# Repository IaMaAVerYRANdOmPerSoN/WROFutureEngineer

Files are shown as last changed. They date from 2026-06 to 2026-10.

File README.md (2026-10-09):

# WRO 2026 Future Engineers – TEAM APOSTLA

## Project Overview
This repository contains the complete documentation, code, design files, and test records for our **WRO 2026 Future Engineers** self-driving car project.

This repo is organized to show:
- how our robot is mechanically designed
- how power and sensors are arranged
- how the software is structured
- how engineering decisions were made
- how another team could reproduce the robot

---

## Team Members

<p align="center">
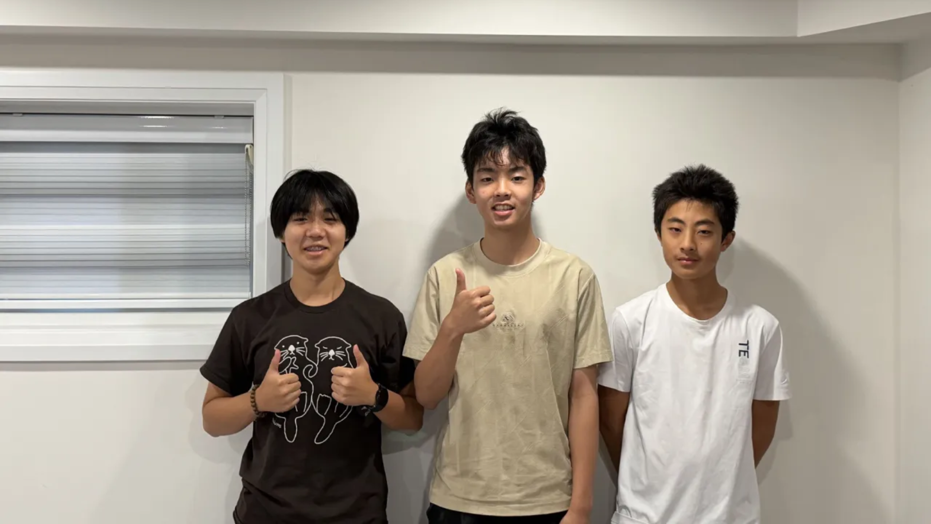
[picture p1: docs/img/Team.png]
  
</p>
<p align="center"><i>Explorer Robotics — WRO Future Engineers 2026</i></p>

---

We are a three-person team from Explorer Robotics in Whitby, Ontario, Canada. We have been competing in WRO for several years. This year we set out to build a fully autonomous self-driving robot from scratch, designing our own chassis, differential gear system, and vision pipeline.

## Elvis Wang
<table>
<tr>
  <td align="center" width="40%">
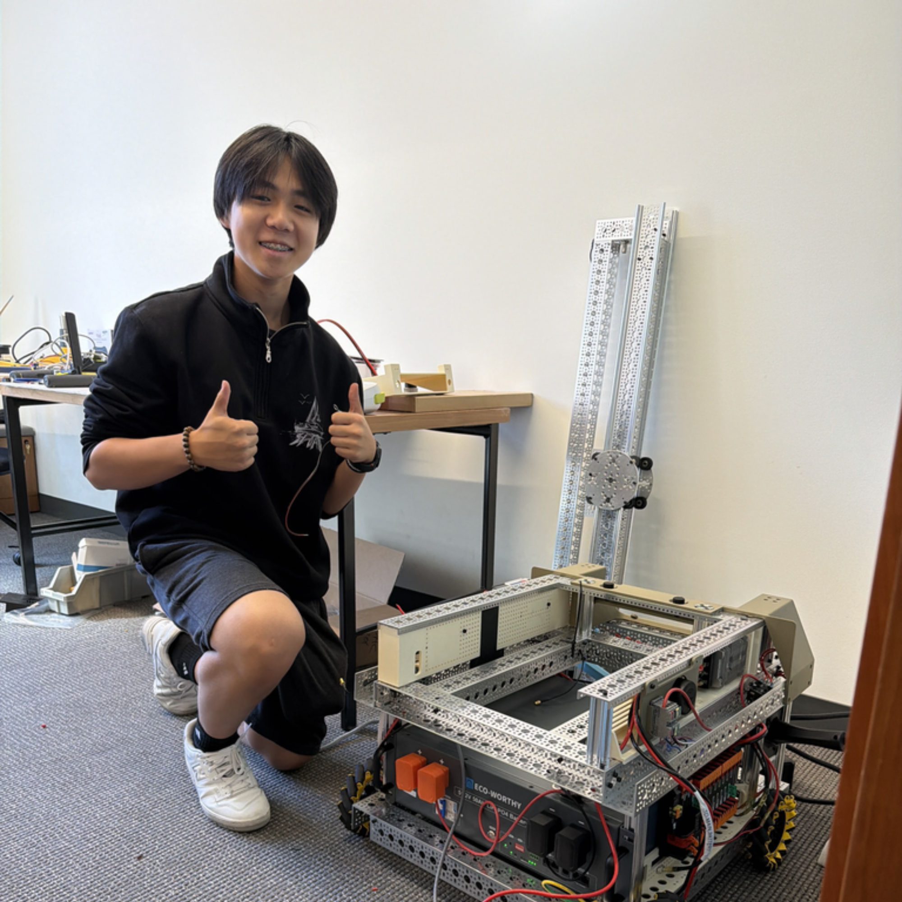
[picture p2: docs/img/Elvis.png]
    <br>
    <em>Elvis</em>
  </td>

  <td valign="top" width="60%">

  ### Information
  - *I love building!!!!!!!*
  - 15 years old
  - Hi, my name is Elvis. I'm 15. I enjoy building and 3D modeling various objects with Fusion 360. I've been with Explorer Robotics ever since I was 8 years old.
  </td>
</tr>
</table>

---

## Michael Xie
<table>
<tr>
  <td align="center" width="40%">
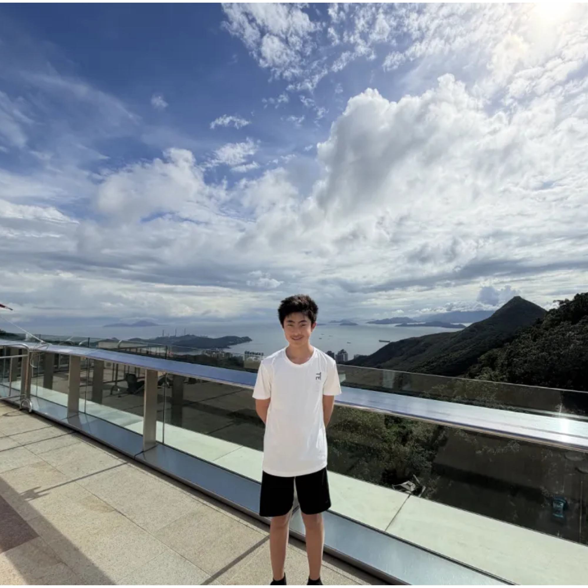
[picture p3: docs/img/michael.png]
    <br>
    <em>Michael</em>
  </td>

  <td valign="top" width="60%">

  ### Information
  - *I love coding!!!!!!*
  - 14 years old
  - I'm Michael. I'm 14, love coding and solving problems. I've been involved in WRO for several years and enjoy using my programming skills to help our team build and improve our robot.
  </td>
</tr>
</table>

---

## Ryan Rao
<table>
<tr>
  <td align="center" width="40%">
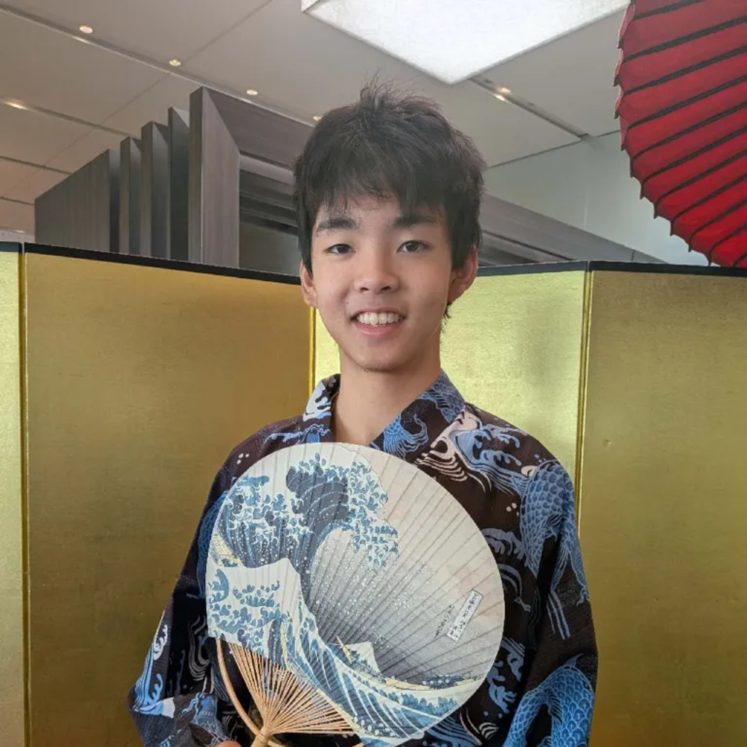
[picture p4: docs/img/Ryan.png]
    <br>
    <em>Ryan</em>
  </td>

  <td valign="top" width="60%">

  ### Information
  - *I love dogs*
  - 15 years old
  - Hi! I'm Ryan. I'm 15, love to write, play badminton, listen to music, and travel. I've been involved in robotics for nearly a decade and participated in both FLL and WRO Robo Mission.
  </td>
</tr>
</table>

## Coach Rice
<table>
<tr>
  <td align="center" width="40%">
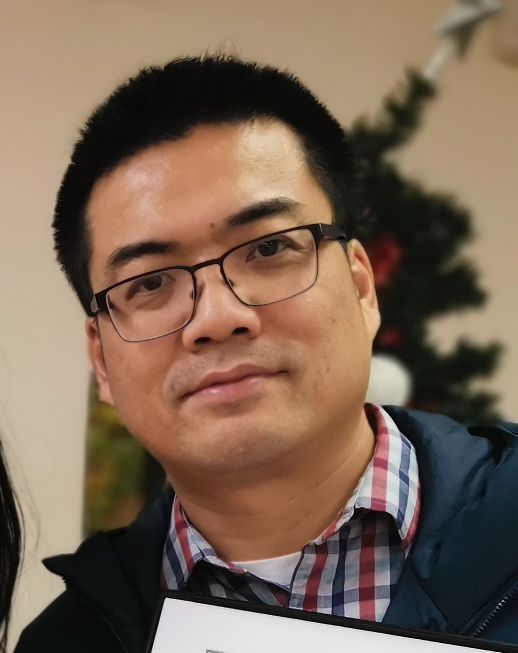
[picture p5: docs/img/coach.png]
    <br>
    <em>Coach Rice</em>
  </td>

  <td valign="top" width="60%">

  ### Information
  - Head coach of Robotics Competitions, including FLL (First LEGO League),  WRO (World Robotics Olympiad) Robo Sports, Future Engineers, and Robo Mission. Led teams in winning multiple national, international robotics, and programming awards.
  - Over 20 years of IT industry experience as a software engineer working internationally.
  - MSc in Electrical & Computer Engineering from the University of Alberta.
  - BSc in Mathematics from Peking University.
  - Founder of Explorer Robotics, a local robotics club in Ajax and Whitby, teaching coding, AI, robotics, etc.
  </td>
</tr>
</table>



---

## Robot Summary

> Our robot is a self-driving car built for the WRO 2026 Future Engineers challenge. It uses one downward-angled camera to spot track walls, corner lines, and colored obstacle pillars, and follows the track using a state-machine control loop. The robot runs on a Raspberry Pi 5 for vision, an Arduino Nano for motor and servo control, a Furitek Micro Komodo 1212 brushless motor that drives the rear wheels through a differential gearbox, and rack-and-pinion steering run by an HS-5055MG servo. Our design is simple and reliable, using one sensor for all detection and a sturdy build that's easy to fix during competition.

---

## Journal
- [View Journal](docs/journal/CHANGELOG.md)
- [View Journal PDF](docs/journal/CHANGELOG.pdf)

---

## Table of Contents

- [Project Overview](#project-overview)
- [Team Members](#team-members)
- [Robot Summary](#robot-summary)
- [Repository Structure](#repository-structure)
  - [Main Files](#main-files)
  - [Documentation](#documentation)
  - [Other Project Assets](#other-project-assets)
- [1. Mechanical Design](#1-mechanical-design)
  - [Images of Robot](#images-of-robot)
  - [Structural Design](#structural-design)
    - [Old Design](#old-design)
    - [Improvements](#improvements)
    - [Changes](#changes)
  - [3D Printed Parts](#3d-printed-parts)
  - [Full Robot](#full-robot)
- [2. Power and Sensor Architecture](#2-power-and-sensor-architecture)
  - [Power](#power)
  - [Voltage and Current Requirements](#voltage-and-current-requirements)
    - [5V Rail (Raspberry Pi, Arduino, Servo)](#5v-rail-raspberry-pi-arduino-servo)
    - [7.4V Rail (Motor)](#74v-rail-motor)
    - [Total Battery Power and Current](#total-battery-power-and-current)
    - [Runtime Estimate](#runtime-estimate)
  - [Sensors](#sensors)
  - [Compute](#compute)
  - [Summary](#summary)
- [3. Software Architecture and Strategy](#3-software-architecture-and-strategy)
  - [Software](#software)
  - [Architecture](#architecture)
  - [Config](#config)
  - [Vision](#vision)
    - [Wall Following](#wall-following)
    - [Obstacle Detection](#obstacle-detection)
  - [Hardware Interfaces](#hardware-interfaces)
  - [Challenge Running](#challenge-running)
    - [Open Challenge](#open-challenge)
    - [Obstacle Challenge](#obstacle-challenge)
  - [Running the Robot](#running-the-robot)
- [4. Systems Engineering and Design Decisions](#4-systems-engineering-and-design-decisions)
  - [Constraints](#constraints)
  - [Trade-offs](#trade-offs)
  - [Design Iteration](#design-iteration)
  - [Risk Analysis](#risk-analysis)
  - [Subsystem Interactions](#subsystem-interactions)
  - [Summary](#summary-1)
- [5. Reproducibility](#5-reproducibility)
  - [Software Setup](#software-setup)
  - [Hardware Setup](#hardware-setup)
  - [Testing](#testing)
  - [Summary](#summary-2)
- [Testing and Validation](#testing-and-validation)
- [Media and Visual Documentation](#media-and-visual-documentation)
  - [Diagrams](#diagrams)
  - [Videos](#videos)
- [CAD and Wiring Files](#cad-and-wiring-files)
- [Version History](#version-history)
- [Contribution and Documentation Rules](#contribution-and-documentation-rules)
- [Final Notes](#final-notes)
- [View Journal](docs/journal/CHANGELOG.md)

---
### GitHub Releases
[GitHub releases page](https://github.com/IaMaAVerYRANdOmPerSoN/WROFutureEngineer/releases/tag/v0.1.0)
- Source Code
- Cad File

---

## Repository Structure

### Main Files
- `README.md` – main project overview and navigation
- `LICENSE` – repository license
- `.gitignore` – ignored local/generated files
- `requirements.txt` – Python dependencies

### Documentation
- `docs/01_mechanical/` – mobility and mechanical design
- `docs/02_power_sensors/` – power system and sensor architecture
- `docs/03_software/` – software design and obstacle strategy
- `docs/04_systems_engineering/` – engineering decisions, trade-offs, and risks
- `docs/05_reproducibility/` – build, setup, assembly, and testing workflow
- `docs/journal/` – dated engineering journal (Markdown + PDF export)
- `docs/img/` – images referenced throughout the docs (robot photos, diagrams, team photos)
- `docs/plan.md`, `docs/shoppingList.md`, `docs/coach_comments.md` – supporting planning docs

**Other top-level folders:**
- `ArudinoServer/` – PlatformIO firmware for the Arduino (low-level motor/servo control)
- `PiClient/` – Python code on the Raspberry Pi
    - `src/` – main vision processing, control, and Arduino communication logic
    - `src_min/` – a minimal/leaner variant of the same modules
    - `utils/tools/` – standalone calibration and debug tools (contours, manual control)
    - `tests/` – test and experiment scripts
- `EDA/` – KiCad PCB project 
    - `FAB/` – fabrication outputs (Gerbers, BOM, pick-and-place positions)
    - `lib/` – imported component symbol/footprint libraries

---

# 1. Mechanical Design
This section explains the physical design of the robot, including chassis layout, steering, drivetrain, torque/speed reasoning, and mechanical improvements over time.

---

### Files
- [`docs/mechanical/mechanical_reasoning.md`](docs/01_mechanical/mechanical_reasoning.md)
- [`docs/mechanical/mechanical_iterations.md`](docs/01_mechanical/mechanical_iterations.md)
- [`docs/mechanical/torque_speed_reasoning.md`](docs/01_mechanical/torque_speed_reasoning.md)

---

- **Dimentions**: 24cm length 10cm wide 28cm high
    - [Dimentions reasoning](docs/01_mechanical/mechanical_reasoning.md#size-reasoning)
- **Drive Motor**: Furitek Micro Komodo 1212 Stepper Motor
    - [Motor reasoning](docs/01_mechanical/mechanical_reasoning.md#motor-selectionmotor-selection)
- **Steering Motor**: HS-5055MG 11.9g Metal Gear Digital Micro Servo
    - [Steering reasoning](docs/01_mechanical/mechanical_reasoning.md#servo-motor)

### Images of Robot
| | |
|:---:|:---:|
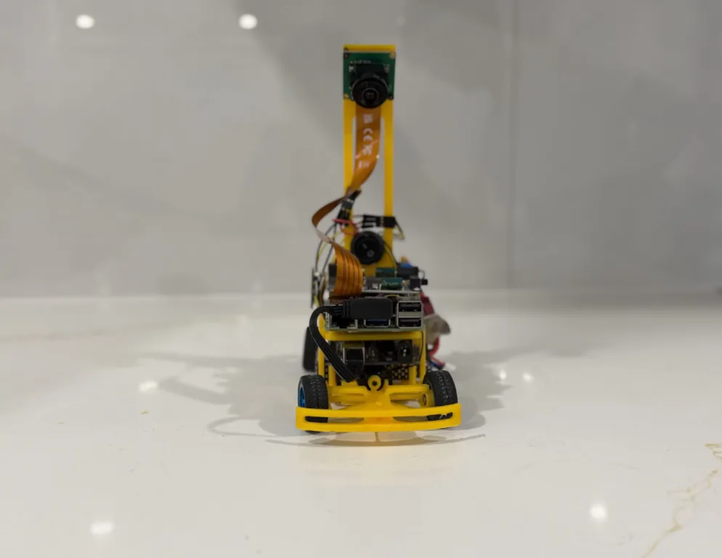
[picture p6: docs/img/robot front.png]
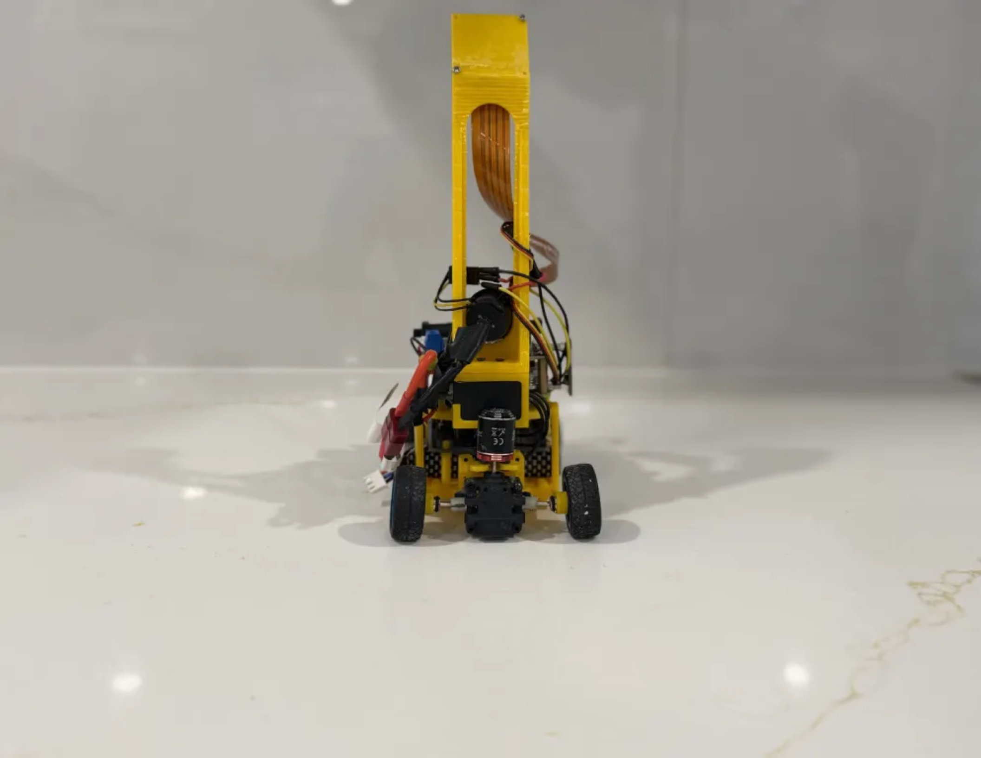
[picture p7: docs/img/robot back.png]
|  |  |
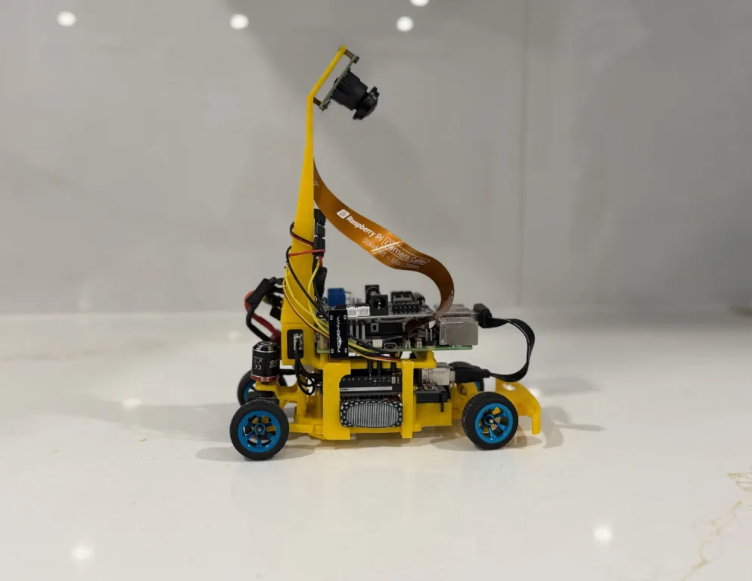
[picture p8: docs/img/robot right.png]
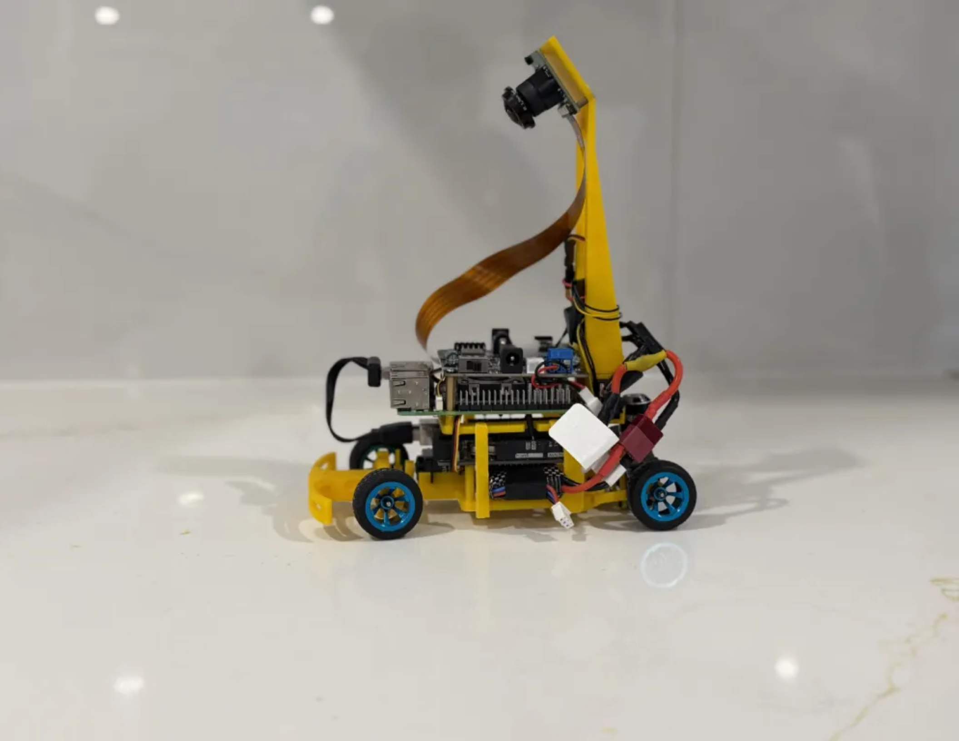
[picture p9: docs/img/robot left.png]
|  |  |
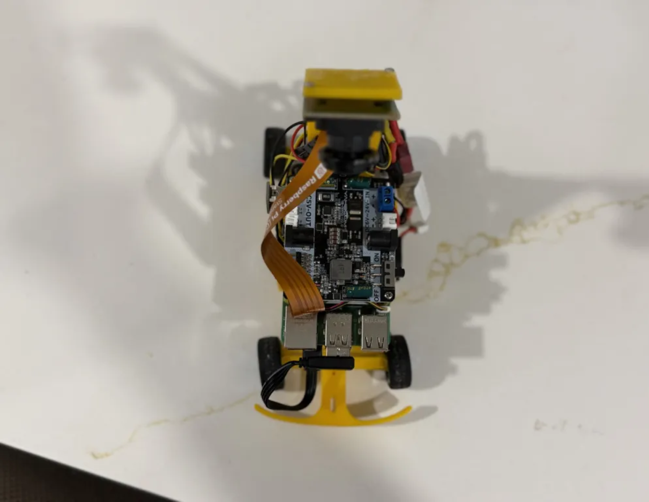
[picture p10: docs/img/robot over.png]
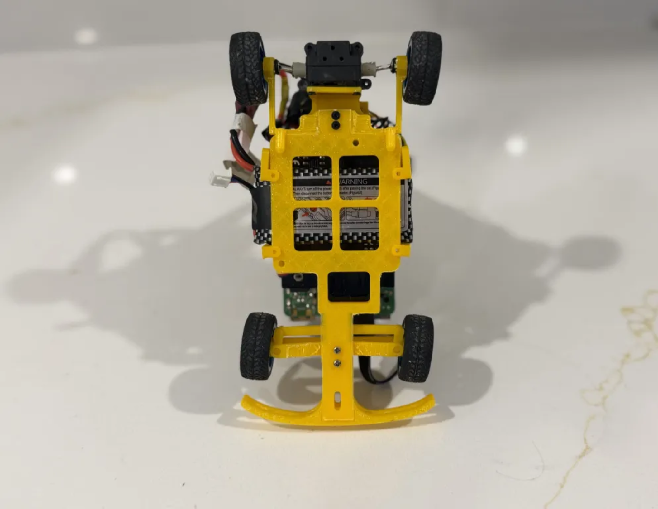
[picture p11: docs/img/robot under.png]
|  |  |

---

- **Drive System**: We use rear wheel drive, means the motor's power is transmitted to the back wheels rather than the front.
    - [Why RWD?](docs/01_mechanical/mechanical_reasoning.md#drive-system)
- **Steering type:** Parallel (Zero-Ackermann), Both front wheels turn at the same angle instead of the inner wheel turning more sharply than the outer. It does cause slight tire scrub during turns but it is acceptable on a small lightweight robot on a smooth mat.
    - [Why Parallel Zero-Ackermann?](docs/01_mechanical/mechanical_reasoning.md#steering-system)
### Structural Design
To get our current design, we took inspiration from our previous robot we used last year in Future Engineers.

#### Old Design
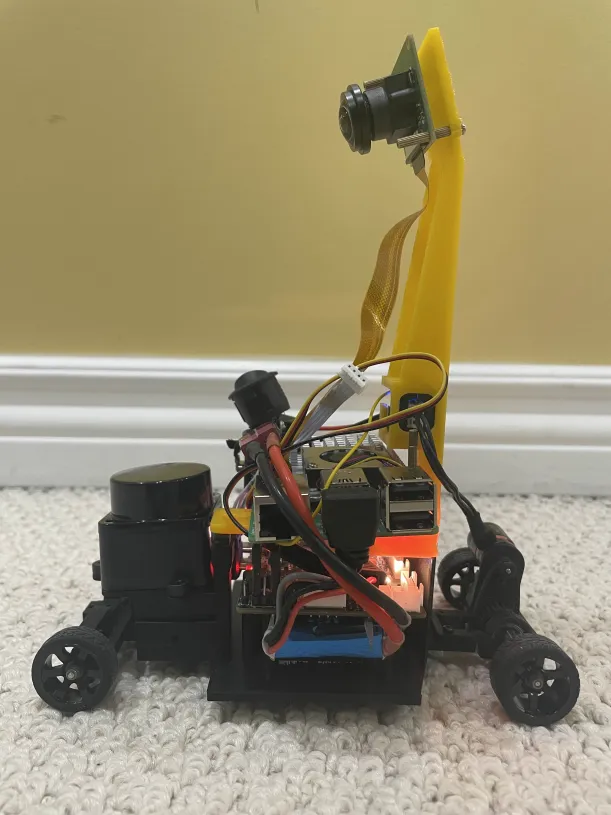
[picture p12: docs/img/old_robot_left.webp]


#### Improvements
- Make the robot thinner for more clearence and better weight distribution
- More supports on the sides of the robot (we only had 2)

---

#### Changes
- Rotating the Raspiberry Pi 90 degrees would allow for a slimmer design
- Implimenting more supports on the sides of the robot
- We use the Arduino Nano instead of Hiwonder
- Changed the camera angle and added a place for the stepdown voltage



### 3D Printed Parts

- **Turning System**: Servo-actuated rack and pinion steering with a curved front bumper for wall sliding in the obstacle challenge. The servo connects to the steering rack via a servo horn and tie rods, rotating the servo horn pushes or pulls the tie rods, which turn the front wheels left or right.
    - [Turning system iterations](docs/01_mechanical/mechanical_iterations.md#turning-system)

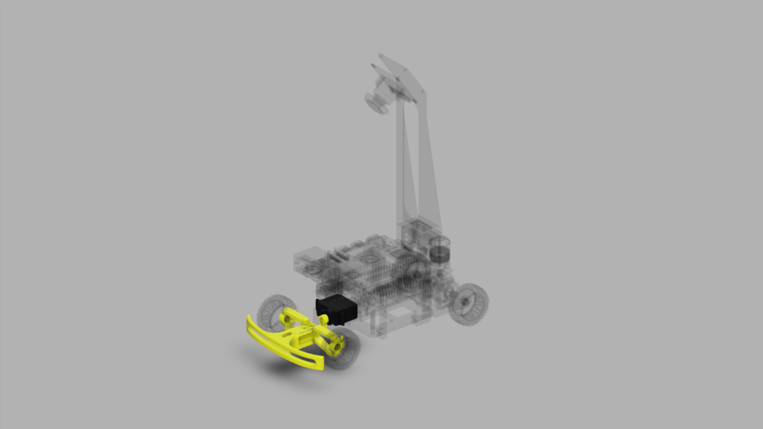
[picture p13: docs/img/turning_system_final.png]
Turning System


- **Raspberry Pi 5 Layout, Camera Mount, and ESC**: Slim rotated design with a separated camera tower angled at 35 degrees downward. The ESC is mounted inside the same assembly to keep electronics consolidated.
    - [RP5 layout and camera mount iterations](docs/01_mechanical/mechanical_iterations.md#raspberry-pi-5-layout-and-camera-mount)

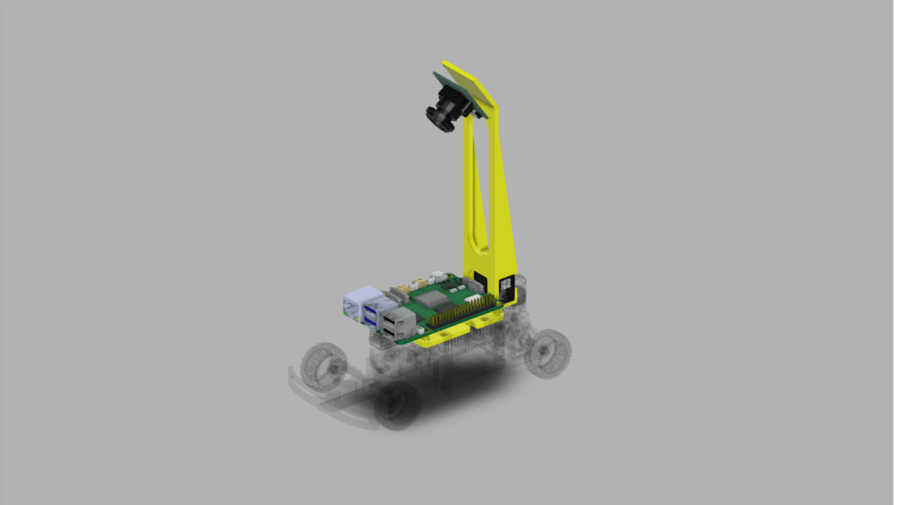
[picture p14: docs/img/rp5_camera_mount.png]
RP5 and Camera Mount


- **Arduino Nano Layout**: Main chassis plate holding the Arduino, servo, and front assembly; redesigned for compactness across four versions
    - [Arduino layout iterations](docs/01_mechanical/mechanical_iterations.md#europe-design)

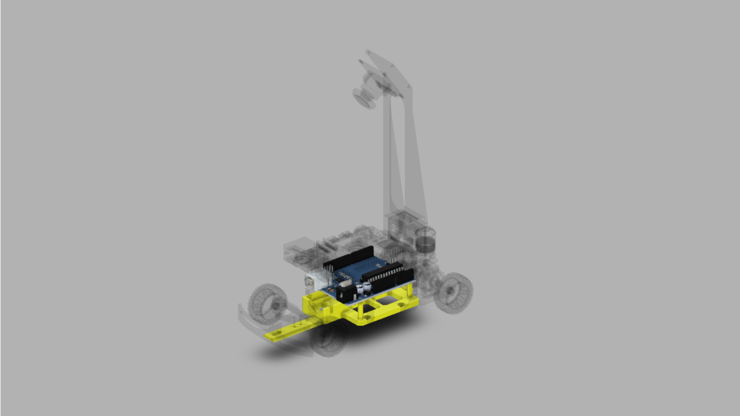
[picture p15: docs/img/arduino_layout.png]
Arduino Layout


- **Connectors**: 3D printed C-shaped connectors replacing brass standoffs to speed up assembly and disassembly
    - [Connector iterations](docs/01_mechanical/mechanical_iterations.md#connectors)

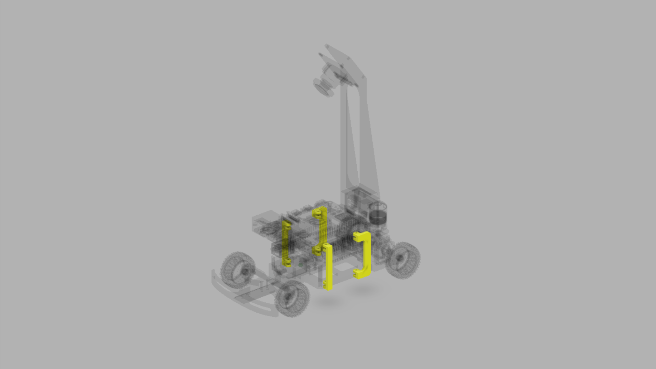
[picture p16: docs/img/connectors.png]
Connectors


- **Furitek Micro Komodo 1212**: Brushless motor rated at 3450 KV and 120W; drives the rear wheels through the differential gearbox
    - [Motor reasoning](docs/01_mechanical/mechanical_reasoning.md#motor-selection)

- **Differential Gear System**: Custom-designed differential allowing the rear wheels to spin at different speeds during turns; went through multiple iterations before settling on an off-the-shelf gearbox

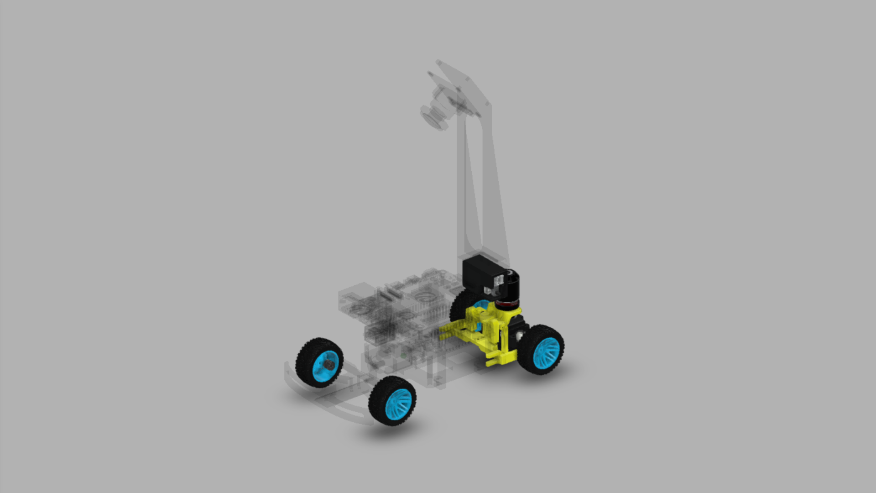
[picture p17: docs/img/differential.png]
Drivetrain


- **Wheels**: 35mm rubber wheels chosen to raise the chassis to give the differential adequate ground clearance
    - [Wheel and torque reasoning](docs/01_mechanical/torque_speed_reasoning.md)

- **Ball Bearings**: Four 6mm ball bearings pressed into the rear body mount to support the axles and reduce friction

---

### Full Robot

| | |
|:---:|:---:|
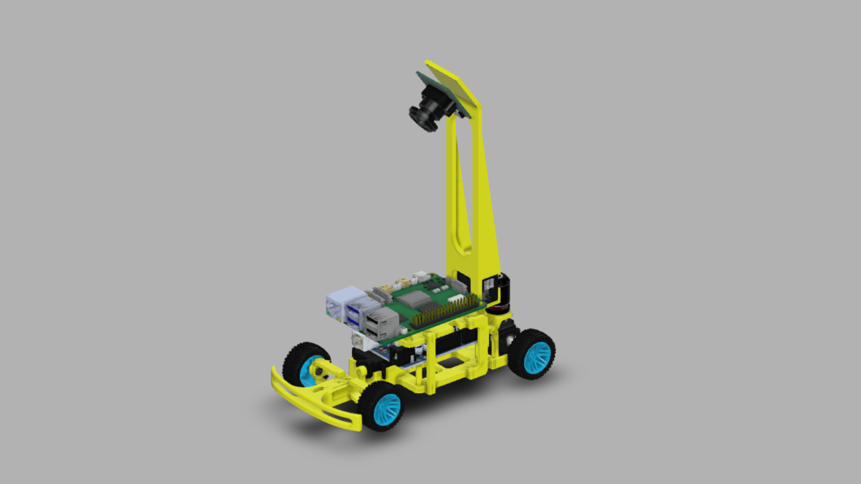
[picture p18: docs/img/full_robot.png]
Full Robot
|  |

---

### Assembly Video

Assembly Video (https://youtu.be/6nG1ul_CTjg)

---

# 2. Power and Sensor Architecture
This section explains how the robot is powered, what sensors are used, where they are placed, and how they are calibrated.

### Files
- [`docs/02_power_sensors/power_architecture.md`](docs/02_power_sensors/power_architecture.md)
- [`docs/02_power_sensors/sensor_selection.md`](docs/02_power_sensors/sensor_selection.md)
- [`docs/02_power_sensors/sensor_placement.md`](docs/02_power_sensors/sensor_placement.md)
- [`docs/02_power_sensors/calibration.md`](docs/02_power_sensors/calibration.md)

---

### Power

Everything starts with a single Gens Ace 1300mAh 2S LiPo battery. From there, power splits into two separate paths so the compute side and the actuator side never interfere with each other.

The first path goes through our Yahboom voltage regulator board, which steps the battery's 7.4V down to a clean 5V. That 5V feeds into the Raspberry Pi 5 through USB-C. The Arduino Nano doesn't connect to the battery at all, it gets powered straight from the Pi over a USB-B cable. The camera is also powered off the Pi, through its flat CSI ribbon cable, which carries both data and power in one connector.

The second path runs through the ESC. The ESC takes power directly from the battery and has its own built-in BEC (battery eliminator circuit) to regulate it. On the output side, the ESC's voltage pin powers the servo, and the ESC also drives the brushless motor directly since the motor doesn't need to be stepped down first.

<p align="center">
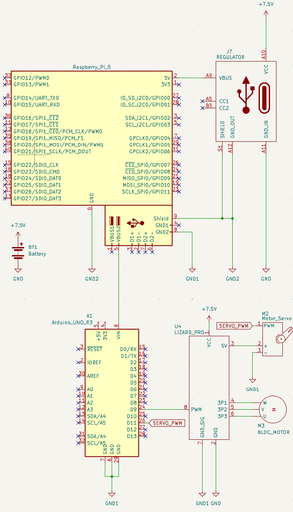
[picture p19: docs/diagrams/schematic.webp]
  
</p>
<p align="center"><i>Full electronics schematic showing power distribution and signal connections.</i></p>

The Raspberry Pi is the brain, it runs the vision pipeline, figures out where objects are, and decides what the robot should do next. The Arduino doesn't make any decisions, it just takes the drive commands the Pi sends it and turns them into precise PWM signals, since the Pi can't reliably time PWM output on its own while it's busy processing frames. The camera is the robot's only sense of the outside world, it feeds every frame the vision pipeline uses to find walls, corners, and pillars.

On the actuator side, the ESC handles throttle control for the drive motor based on the PWM signal it gets from the Arduino, and its BEC also acts as the power source for the servo, so the servo never has to touch the battery directly. The servo itself just turns the front wheels left and right based on the steering commands coming from the Arduino, and the motor is what actually moves the robot forward, spinning the rear wheels through the differential.

- **Battery**: Gens Ace 1300mAh 2S LiPo, 7.4V nominal, 45C discharge
    - [Battery details](docs/02_power_sensors/power_architecture.md#battery)
- **Voltage Regulation**: Yahboom regulator converts 7.4V to 5V for the Raspberry Pi; ESC built-in BEC powers the servo independently
    - [Regulator details](docs/02_power_sensors/power_architecture.md#design-rationale)
- **Main Power Switch**: Smaller switch installed on the main battery rail after the original 20A switch was replaced for easier integration
    - [Power design](docs/02_power_sensors/power_architecture.md#iterations)
- **Estimated Runtime**: ~17 minutes at average load; enough for ~5 full competition runs per charge

## Voltage and Current Requirements

### 5V Rail (Raspberry Pi, Arduino, Servo)

| Component | Current Draw |
|---|---|
| Raspberry Pi 5 | 2.40A |
| Arduino Nano | 0.05A |
| Servo Motor (stall) | 0.70A |
| Camera (OV5647) | 0.25A |
| **Total 5V current** | **3.40A** |

Power at 5V: 3.40A × 5V = **17W**

Accounting for regulator efficiency (80%):
17W ÷ 0.8 = **21.25W** needed from battery for the 5V rail.

---

### 7.4V Rail (Motor)

| Component | Current Draw |
|---|---|
| Drive Motor (average during run) | 3.50A |
| **Total motor current** | **3.50A** |

Power at 7.4V: 3.50A × 7.4V = **25.9W**

---

### Total Battery Power and Current

| Rail | Power |
|---|---|
| 5V rail (via regulator) | 21.25W |
| Motor rail (direct) | 25.9W |
| **Total** | **47.15W** |

Total current from battery:
47.15W ÷ 7.4V = **6.37A**

---

### Runtime Estimate

6.37A average draw from a 1300mAh (1.3Ah) battery at 80% usable capacity:

(1.3Ah × 0.8) ÷ 6.37A = **~0.16 hours (~10 minutes)**

In practice the robot lasts significantly longer because:
- The motor draws far less than stall current at competition speeds (30-40% throttle)
- The Raspberry Pi rarely hits full load simultaneously with peak motor draw
- The servo is at stall current only momentarily during sharp turns
- The regulator efficiency is typically closer to 85-90% under real load

At realistic average loads (~4A total), the expected runtime is approximately **17 minutes**, sufficient for ~5 full competition runs per charge.

Because of the decently short battery life, we have had between 4-5 batteries.

---

### Sensors

- **Camera (OV5647)**: Detects walls, corner lines, and colored pillars via CSI-2 at 640x480 up to 62.50 fps
    - [Camera selection](docs/02_power_sensors/sensor_selection.md#camera--ov5647)
    - [Camera placement](docs/02_power_sensors/sensor_placement.md)
- **IMU**: Detects rotation and acceleration
    - [IMU purpose](docs/02_power_sensors/sensor_selection.md#camera--ov5647)
      
---

### Compute

- **Raspberry Pi 5 (8GB)**: Main compute unit running the vision pipeline, control loop, and Arduino communication
    - [Raspberry Pi details](docs/02_power_sensors/sensor_selection.md#raspberry-pi-5-8gb)
- **Arduino Nano**: Handles PWM output to ESC and servo; receives drive commands from the Pi over USB serial
    - [Arduino details](docs/02_power_sensors/sensor_selection.md#arduino-nano)

---

### Actuators

- **ESC**: Furitek Lizard Pro 30A/50A ESC
    - [ESC reasoning](docs/02_power_sensors/power_architecture.md#electronic-speed-controller)
- **Drive Motor**: Furitek Micro Komodo 1212 Stepper Motor
    - [Motor reasoning](docs/01_mechanical/mechanical_reasoning.md#motor-selectionmotor-selection)
- **Steering Motor**: HS-5055MG 11.9g Metal Gear Digital Micro Servo
    - [Steering reasoning](docs/01_mechanical/mechanical_reasoning.md#servo-motor)
---

## Risks and Mitigation

- **Voltage drop:** The 45C discharge rating minimizes voltage sag under peak current draw. Battery voltage is monitored during practice runs to identify cell degradation early.
- **Brownout:** The Pi is powered through a Yahboom voltage regulator board rather than directly from the battery, isolating it from motor-induced voltage dips. A regulator with sufficient headroom above the Pi's peak draw was selected. We may have broken one of our raspberry pi's because we forgot the regulator...
- **Electrical noise:** Motor and ESC wiring are routed away from signal wires. The serial communication lines between the Pi and Arduino are kept short.
- **Loose connectors:** All connectors are secured with heat shrink. Once, one of our wires got caught in the gear system causing damage, leading to a short circuit. All wiring has since been replaced.
- **Overheating:** The ESC and motor are mounted with airflow clearance. Competition runs are under 3 minutes, well within thermal limits. The Raspberry Pi fan is configured to always run after the temperature sensor proved unreliable on our unit.
- **Power spikes from motors / servos:** The ESC BEC powers the servo independently from the motor rail. The dedicated regulator for the Pi prevents motor spikes from reaching the compute system.

---

### Summary
- battery: Gens Ace 1300mAh 2S LiPo (7.4V, 45C)
- voltage regulation: Buck regulator for Pi (5V); ESC BEC for servo
- main sensors: OV5647 camera (CSI-2)
- sensor placement strategy: Camera mounted at front with downward tilt for field of view
- calibration approach: HSV color thresholds tuned under competition lighting using interactive tuning tools in `utils/`

---

# 3. Software Architecture and Strategy

## Software

This section explains the software that runs on the Raspberry Pi, including how the processes are structured, how the robot detects walls and obstacles, and how drive commands are sent to the Arduino.

---

### Files
- [`docs/03_software/architecture.md`](docs/03_software/architecture.md)
- [`docs/03_software/challenge)running.md`](docs/03_software/challenge_running.md)
- [`docs/03_software/config.md`](docs/03_software/config.md)
- [`docs/03_software/hardware_interfaces.md`](docs/03_software/hardware_interfaces.md)
- [`docs/03_software/state_machine.md`](docs/03_software/state_machine.md)
- [`docs/03_software/vision.md`](docs/03_software/vision.md)

---

## Architecture

Three processes run at the same time, camera, vision, and main control. The camera writes frames into shared memory, the vision process reads them and finds walls and obstacles, and the main process runs the state machine and sends commands to the Arduino. The system always uses the freshest data; stale frames and commands are dropped automatically.

- **Camera Process**: Captures frames and writes them into shared memory
    - [Architecture details](docs/03_software/architecture.md)
- **Vision Process**: Reads frames and finds walls and obstacles
    - [Vision details](docs/03_software/vision.md)
- **Main Process**: Runs the state machine and sends drive commands to the Arduino
    - [Runner details](docs/03_software/challenge_running.md)

<p align="center">
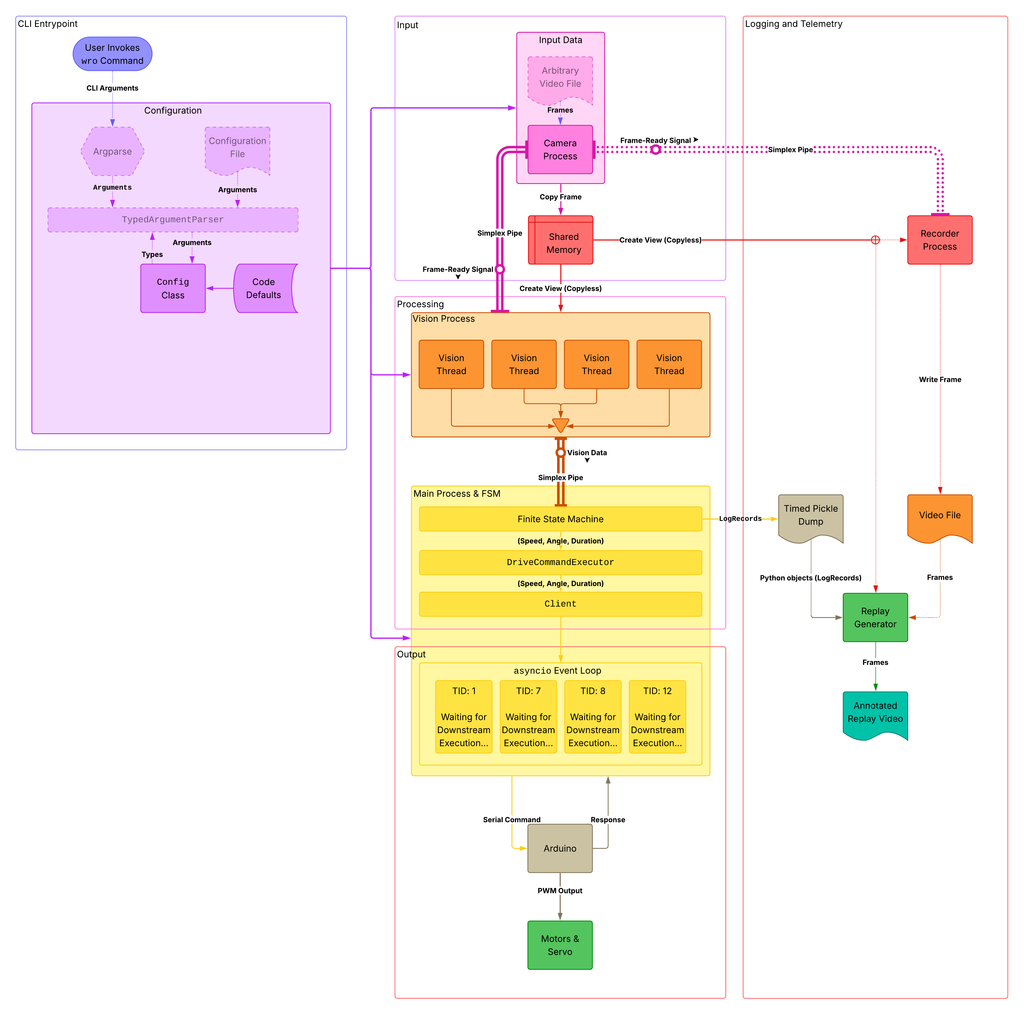
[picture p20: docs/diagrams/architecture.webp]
  
</p>
<p align="center"><i>Full software architecture diagram.</i></p>

---

## Config

All settings are stored in `piclient.toml`. Nothing is hardcoded — speed, PD gains, HSV thresholds, serial ports, and ROI sizes are all in the config file. Once the robot starts, the config is locked and cannot be changed mid-run.

- **Settings file**: `piclient.toml` at the root of the repo
    - [Config details](docs/03_software/config.md)
- **Override priority**: CLI flag > environment variable > `piclient.toml` > code defaults

---

## Vision

### Wall Following

`open_challenge.py:95-104` the vision pipeline counts the number of black pixels in the left, right, and center regions of the image. The difference between right and left distance is fed into a PD controller (`wall_follow.tick(right - left)`), and the output is sent as a steering command via `client.drive_motors(...)`. If the right wall is further than the left, the correction steers left, and vice versa. It only cares about relative position, not absolute distance, which is why the perspective transform can be skipped. Camera distortion does not change which wall is closer.

### Obstacle Detection

`vision_processing.py:100-106`: red and green pillars are found the same way as walls, but contours (as NumPy arrays) are used instead of simple pixel counts. Once a pillar is found, `_get_target` calculates a target x position by offsetting the pillar's x position proportionally to the width of the pillar. A separate PD controller (`obstacle_avoid`) steers toward that target x position rather than centering between walls, while maintaining 20% wall-follow weight to keep general awareness. This only runs in `obstacle_challenge.py`'s "obstacle_avoid" state, and only when `obstacles` is non-empty. Otherwise, it falls back to plain wall following.

- **Open Challenge**: Counts black pixels in left, right, and center regions. More black pixels means the wall is closer. Corner detection triggers when the center region fills up.
    - [Open challenge vision details](docs/03_software/vision.md#open-challenge)
- **Obstacle Challenge**: Finds red and green pillars using HSV color detection and calculates an offset target x position to steer toward the gap between the pillar and the wall.
    - [Obstacle challenge vision details](docs/03_software/vision.md#obstacle-challenge)

---

## Hardware Interfaces

- **Camera**: Runs in its own process, writes frames directly into shared memory with no copying
    - [Camera details](docs/03_software/hardware_interfaces.md#camera)
- **Arduino Client**: Sends serial commands with transaction IDs so multiple commands can be in flight at once
    - [Arduino client details](docs/03_software/hardware_interfaces.md#arduino-client)
- **DriveCommandExecutor**: Sits between the control loop and the Arduino, only the latest command is sent, stale commands are thrown away
    - [DriveCommandExecutor details](docs/03_software/hardware_interfaces.md#drivecommandexecutor)

---

## Challenge Running
The robot uses a finite state machine (FSM) to decide what to do at any given moment. Each state has a specific trigger that causes the robot to enter it and a specific action it takes while in that state. The FSM runs once per camera frame, so the robot is constantly re-evaluating which state it should be in based on the latest vision data.

### Open Challenge

| State | Trigger | Action |
|---|---|---|
| Straight | Default | Wall follow with PD controller |
| Turn | Black fill detected ahead | Hard steer toward missing wall |
| Final Turn | Last turn of last lap | Same as Turn |
| Final Straight | After final turn | Drive to stop |

- [Open challenge runner details](docs/03_software/challenge_running.md#open-challenge)

### Obstacle Challenge

| State | Trigger | Action |
|---|---|---|
| Straight | Default | Wall follow with PD controller |
| Turn | Corner detected | Hard steer toward missing wall |
| Obstacle Avoid | Vision returns a pillar target | Steers toward the gap between pillar and wall |
| Parallel Parking | Vision returns a parking lot target and the 3rd lap is complete | Steers toward the parking lot and executes a parallel parking maneuver |

Same as the open challenge with one extra state. When a pillar is detected, the robot steers toward the gap between the pillar and the wall. Green pillars are passed on the left, red on the right.

- [Obstacle challenge runner details](docs/03_software/challenge_running.md#obstacle-challenge)

---

## Running the Robot

```bash
wro --GeneralConfig.CHALLENGE open
wro --GeneralConfig.CHALLENGE obstacle
```

Full auto-generated API docs: https://apostla-api-reference.web.app/
---

# 4. Systems Engineering and Design Decisions
This section explains how the robot was developed as an integrated system and how trade-offs were evaluated.

- **Engineering Journal**:
The journal is best viewed on GitHub where all links are clickable. A PDF version is also available for submission.
    - [View Journal](docs/journal/CHANGELOG.md)
    - [View Journal PDF](docs/journal/CHANGELOG.pdf)

### Files
- [`docs/04_systems_engineering/subsystem_interactions.md`](docs/04_systems_engineering/subsystem_interactions.md)
- [`docs/04_systems_engineering/constraints_tradeoffs.md`](docs/04_systems_engineering/constraints_tradeoffs.md)
- [`docs/04_systems_engineering/risk_analysis.md`](docs/04_systems_engineering/risk_analysis.md)
- [`docs/04_systems_engineering/iteration_cycles.md`](docs/04_systems_engineering/iteration_cycles.md)

### Constraints

The robot must satisfy four levels of constraints in order of priority:

- **WRO rules compliance**: Size, mass, power, and mechanical limits must be respected at all times. The robot must start, stop, and reset reliably.
- **Score maximization**: The robot must complete challenge objectives as reliably as possible, minimize recovery time, and avoid oscillations and false detections.
- **Simplicity and reliability**: Each subsystem has a clear single purpose. The system degrades gracefully under sensor noise and is easy to debug during competition setup.
- **Speed**: The camera pipeline, control loop, and serial interface must keep up with the required frame rate without creating stale-data backlogs.
    - [Full constraint tree](docs/04_systems_engineering/constraints_tradeoffs.md#constraint-tree)

---

### Trade-offs

Trade-offs are evaluated against the constraint hierarchy, a trade-off that violates a higher-level constraint is rejected regardless of its other benefits. Hardware trade-offs are treated with more caution than software trade-offs because they are harder to reverse. A quick preliminary solution is always tested on the track before committing to a final design.

- **Single camera over multiple sensors**: Reduces weight, cost, and synchronization complexity. HSV calibration and track testing address the lighting sensitivity limitation.
- **Rear-wheel drive over four-wheel drive**: Simpler drivetrain leaves more room for reliable software and testing.
- **Latest-wins command scheduling**: A fresh steering correction is more valuable than guaranteed delivery of an outdated command.
- **Namespace package architecture**: More complex to set up but provides clear interfaces, independent distribution, and sustainable long-term maintainability.
    - [Full trade-off analysis](docs/04_systems_engineering/constraints_tradeoffs.md#trade-offs)

---

### Design Iteration

Major design decisions are modelled as a Directed Acyclic Graph, early hardware choices form root nodes that constrain downstream software and tuning decisions. Two case studies show how this plays out in practice:

- **Differential gear**: Five iterations from an adapted GrabCAD design through three custom printed versions to a salvaged RC gearbox. Each iteration exposed a new constraint, material limits, tolerance stacking, component sizing, that drove the next architectural shift.
- **Python packaging**: Four iterations from a flat src directory to a namespace package architecture with independently distributable components, driven by the need for clear interfaces between the camera, vision, control, and recording subsystems.
    - [Full iteration history](docs/04_systems_engineering/iteration_cycles.md)

---

### Risk Analysis

Risks are identified through track telemetry, SPICE circuit simulation, and rulebook audits. Each risk is placed on a likelihood vs. impact matrix to prioritize fixes. Mitigation follows the same iterative process as design, a quick patch is tested on the track first, then refined into the final solution.

- **Risk lifecycle**: Identify → Evaluate → Mitigate → Validate on track → Iterate
    - [Full risk analysis](docs/04_systems_engineering/risk_analysis.md)

---

### Subsystem Interactions

The robot's performance is determined by how its subsystems work together. Key interactions:

- **Mechanical and control**: Steering range, drive speed, camera height, and PD gains must be tuned together, a software improvement is only useful if the drivetrain can produce the requested response.
- **Power and electrical**: Motor and servo current spikes can cause Raspberry Pi brownouts. The regulator and wiring separate high-current actuator loads from compute power.
- **Perception and behavior**: The camera is the only active sensor. Vision runs in a separate process and signals the main loop when fresh data is ready. Corner detection requires several consecutive frames to filter noise.
- **Software and communication**: The DriveCommandExecutor uses latest-wins scheduling so serial latency never creates a backlog of stale commands.
    - [Full subsystem interaction map](docs/04_systems_engineering/subsystem_interactions.md)

---

### Summary
- biggest engineering constraints: WRO size and mass limits; camera-only perception under variable lighting; PLA material limits for 3D printed gears
- main trade-offs: Single camera vs. multi-sensor; RWD vs. AWD; namespace packages vs. flat src; printed differential vs. off-the-shelf gearbox
- most important decisions: Latest-wins command scheduling; parallel process architecture; namespace package distribution
- major risks: Differential gear failure; Raspberry Pi brownout; camera detection failure under competition lighting
- how the robot improved through iteration: Each failure exposed a new constraint that drove the next design, five differential versions, four packaging versions, and continuous PD and HSV tuning on the track

---

# 5. Reproducibility
This section explains how another team could rebuild, set up, and test the robot.

### Files
- [`docs/05_reproducibility/build_guide.md`](docs/05_reproducibility/build_guide.md)
- [`docs/05_reproducibility/bill_of_materials.md`](docs/05_reproducibility/bill_of_materials.md)
- [`docs/05_reproducibility/setup_guide.md`](docs/05_reproducibility/setup_guide.md)
- [`docs/05_reproducibility/building_from_source.md`](docs/05_reproducibility/building_from_source.md)
- [`docs/05_reproducibility/testing_workflow.md`](docs/05_reproducibility/testing_workflow.md)
- [`docs/05_reproducibility/release_notes.md`](docs/05_reproducibility/release_notes.md)

---

### Software Setup

- **Normal install**: Install the prebuilt wheel using pip on Raspberry Pi OS (64-bit, Bookworm or later)
    - [Setup guide](docs/05_reproducibility/setup_guide.md)
- **Build from source**: Clone the repo and build four namespace packages using Python 3.13+. Required if the wheel is not yet published to PyPI.
    - [Building from source](docs/05_reproducibility/building_from_source.md)
- **picamera2**: Not included in the wheel — use the system-wide installation bundled with Raspberry Pi OS. Do not install from source.

```bash
python -m venv --system-site-packages .venv
source .venv/bin/activate
pip install piclient[all]
```

---

### Hardware Setup

- **Bill of materials**: Full component list including electronics, mechanical parts, 3D printed parts, and tools
    - [Bill of materials](docs/05_reproducibility/bill_of_materials.md)
- **Build Guide** How to print, assemble, and build our robot
    - [Build Guide](docs/05_reproducibility/build_guide.md)
---

### Testing

- **Track is the source of truth**: No change is considered valid until tested on the real track. Unit tests and integration tests are automated via CI/CD but cannot replace real-world validation.
- **Hardware testing**: Components are tested directly on the robot. 3D printed parts are rapidly prototyped and tested. Electronics are validated in SPICE simulation before being installed.
- **Software testing**: All pull requests are automatically tested by the CI/CD pipeline. Logs and video footage are used to diagnose failures.
- **Fallback plan**: Spare parts are kept for all critical components. All packages are versioned and uploaded to PyPI for quick rollback. A fully assembled electronics backup is kept ready for competition.
    - [Testing workflow](docs/05_reproducibility/testing_workflow.md)

---

### Summary
- how to build the robot: See bill of materials and build guide
- how to install software: `pip install piclient[all]` on Raspberry Pi OS Bookworm
- how to calibrate: Run `python -m utils --tool contours control` under competition lighting and update `piclient.toml`
- how to test: Run on track — unit tests via CI/CD, real-world validation required for all changes
- what files are needed to reproduce the system: All STL files in `models/stl/`, config in `piclient.toml`, Arduino firmware in `ArudinoServer/`

## Testing and Validation
Summarize how the robot was tested.

Example points:
- bench tests for hardware
- sensor tests
- steering tests
- lane following tests
- obstacle avoidance tests
- full track tests

Detailed records:
- [`docs/04_systems_engineering/iteration_cycles.md`](docs/04_systems_engineering/iteration_cycles.md)
 - [View Journal](docs/journal/CHANGELOG.md)

---

### Diagrams
<p align="center">
  
</p>
<p align="center"><i>Full software architecture diagram.</i></p>

<p align="center">
  
</p>
<p align="center"><i>Full electronics schematic showing power distribution and signal connections.</i></p>

## API Reference

Full API documentation for every package in this release is at
**[apostla-api-reference.web.app](https://apostla-api-reference.web.app/)**.

### Videos
### Open Challenge Run
Open Challenge Run (https://www.youtube.com/watch?v=WqN3tuj8LFo)

### Obstacle Challenge Run
Obstacle Challenge Run (https://www.youtube.com/watch?v=08cq6RNCGQM)

Suggested folders:
- `docs/images/`
- `docs/diagrams/`

---

## Version History

- [`Journal`](docs/journal/CHANGELOG.md)

---

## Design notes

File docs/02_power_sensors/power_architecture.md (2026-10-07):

# Power Architecture

[Back to README](../../README.md)

---

## Objective

Explain how the robot is powered and why this power system was selected.

---

## Battery

- **Model**: Gens Ace 1300mAh 2S LiPo
- **Voltage**: 7.4V nominal
- **Capacity**: 1300mAh
- **Discharge rating**: 45C
- **Connector**: Deans-T

**Why this battery was selected:**
- 7.4V (2S) sits within the operating range of the Furitek Lizard Pro ESC and Micro Komodo motor. 3S was considered but rejected as it would require aggressive speed limiting in software and increases overcurrent risk.
- 1300mAh provides enough capacity for approximately 5 full competition runs without adding unnecessary weight to the chassis.
- The 45C discharge rating ensures the battery can deliver peak current during hard acceleration without voltage sag that would otherwise destabilize the Raspberry Pi and servo.
- Deans-T connector was chosen for its low resistance and secure connection at high current draw.

> **Note:** A melted Deans-T connector was encountered early in the build due to undersized wiring. All wiring has since been replaced with correctly rated wire. The connector is checked before every run.

---

## Power System Overview

- **Main battery**: Gens Ace 1300mAh 2S LiPo, 7.4V nominal, 45C discharge
- **Main power consumers**: Drive motor (up to 10A), Raspberry Pi (up to 2.4A at full load)
- **Expected runtime**: ~17 minutes at average load (~5 full competition runs per charge)

---

## Power Distribution

- **Direct battery power**: ESC and drive motor draw directly from the battery through the main power rail.
- **Regulated power**: The Raspberry Pi receives 5V from a Yahboom voltage regulator board. This isolates the Pi from voltage fluctuations caused by the motor during acceleration.
- **Servo power**: The ESC's built-in BEC supplies 5V or 6.5V to the servo motor independently from the main motor rail.
- **Camera power**: The OV5647 camera draws 3.3V from the Raspberry Pi's CSI rail.
- **Arduino power**: The Arduino draws 5V from the Raspberry Pi over USB.
- **Voltage step-down**: Yahboom voltage regulator board converts 7.4V battery output to stable 5V for the Raspberry Pi.

---

## Power Diagram

*Insert labeled power diagram here.*

---

## Component Power Table

| Component | Operating Voltage | Estimated Current | Power Source |
|---|---|---|---|
| RC Car Battery (Gens Ace 1300mAh 2S LiPo) | 7.4V nominal | — | Self (source) |
| Drive Motor (Furitek Micro Komodo 1212) | 7.4V–11.1V (2S–3S) | Up to 10A continuous | ESC / Battery |
| ESC (Furitek Lizard Pro 30A/50A) | 7.4V–11.1V (2S–3S) | 30A constant, 50A burst | Battery (direct) |
| Servo Motor (Hitec HS-5055MG) | 4.8V–6.0V | 120mA no-load, 700mA stall | ESC BEC (5V or 6.5V) |
| Raspberry Pi 5 8GB | 5V | 2A–5A (idle ~1A, full load ~2.4A) | Step-down regulator from battery |
| Camera (OV5647 5MP) | 3.3V | ~250mA | Raspberry Pi 5 (CSI / 3.3V rail) |
| Microcontroller (Arduino Nano) | 5V | ~50mA | Raspberry Pi 5 (USB) |
| Power Switch | 7.4V | Up to 20A | In series with battery main rail |

---

## Design Rationale

- **Why this battery was selected:** The Gens Ace 1300mAh 2S LiPo balances capacity, weight, and discharge rate. The 45C rating ensures peak current can be delivered without voltage sag, and 1300mAh is sufficient for multiple competition runs without unnecessary weight.
- **Why this voltage level was selected:** 2S (7.4V nominal) sits within the operating range of the ESC and motor. 3S would require more aggressive software speed limiting and increases overcurrent risk without meaningful benefit for a wall-following robot.
- **Why this regulator setup was selected:** A Yahboom voltage regulator board isolates the Raspberry Pi from motor-induced voltage fluctuations. The ESC's built-in BEC handles servo power separately, further reducing load on the regulator and preventing servo actuation from affecting the Pi's supply.
- **Why this design is safe and reliable:** Each subsystem is powered independently — the motor draws directly from the battery through the ESC, the Pi draws through a dedicated regulator, and the servo draws from the ESC BEC. A motor current spike cannot directly affect the Pi or servo.

---

## Runtime Considerations

- **Estimated average current draw:** ~5.5–6.5A total across all components during a normal competition run.
- **Estimated peak current draw:** ~12–13A during hard acceleration when the motor, Pi vision pipeline, and servo are all active simultaneously.
- **Expected runtime:** Runtime ≈ 1.3Ah × 0.8 ÷ 6A ≈ 17 minutes at average load. The 0.8 factor accounts for the recommended 80% discharge limit on LiPo cells.
- **Factors that reduce runtime:**
  - Aggressive acceleration and high-speed driving
  - Frequent steering corrections
  - Heavy computational load on the Raspberry Pi (vision pipeline at 60fps)
  - Cold ambient temperatures reducing LiPo cell capacity

---

## Iterations

- **Initial power design:** Large 20A toggle switch sourced from school supply; undersized wiring throughout the power harness; no dedicated regulator mount.
- **Problems observed:** Deans-T male connector melted during a test run due to excessive resistance from undersized wiring carrying motor current (Week 14). Step-down voltage regulator short circuited when wires were caught in the motor system; the regulator port broke as a result (Week 19). Large toggle switch was physically difficult to mount cleanly on the chassis.
- **Changes made:** Undersized wiring replaced with correctly rated wire throughout. Large toggle switch replaced with a smaller switch. Deans-T connector replaced. Dedicated mounting location created for the step-down regulator to keep it away from moving parts.
- **Final improvement:** High-current motor wiring is now fully separated from low-current signal and compute wiring. Each subsystem is powered independently. The regulator is physically isolated from the drivetrain to prevent future damage.

---

## Electronic Speed Controller (ESC)  
The ESC is a key component that regulates how the motor receives power. It:  
- Controls the motor's speed  
- Manages direction  
- Ensures safe delivery of voltage and current to the motor

## Furitek Lizard Pro 30A/50A ESC

- **Battery Support:** 2S–3S LiPo
- **BEC:** 5V or 6.5V, 2.5A
- **Constant Current:** 30A
- **Burst Current:** 50A
- **Built-in Power Switch**
- **Dimensions:** 28 × 15.5 mm
- **Weight:** 3.7 g

**Where to Buy:** [Click Here](https://furitek.com/products/combo-of-furitek-lizard-pro-30a-50a-brushed-brushless-esc-for-axial-scx24-with-bluetooth)

This ESC was chosen for its high current capacity, lightweight design, and reliable built-in BEC, making it well-suited for our motor and servo needs.

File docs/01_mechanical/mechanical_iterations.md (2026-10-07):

# 3D Printed Parts

[Back to README](../../README.md)

---

## Turning System

Servo-actuated rack and pinion steering with a curved front bumper for wall sliding in the obstacle challenge.

### Iterations

**Version 1 — Reused from Previous Season**
Carried over from last year's robot. Turning was uniform and robust but the steering horn broke periodically under load.

**Version 2 — Improved Attachability and Steering Horn**
- Redesigned mounting interface to match the robot's base shape, preventing sliding during sharp turns.
- Added a fillet to the steering horn to reduce stress concentration and improve durability.

**Version 3 — Curved Bumper (Final)**
A curved bumper was added to the front of the robot:
- Acts as a shield if the robot contacts a wall.
- Allows the robot to slide off walls cleanly in the obstacle challenge. Without it, the rubber wheels provided too much grip and caused the robot to lodge itself against walls.

<p align="center">
  
</p>
<p align="center"><i>Final version of the turning system showing the curved front bumper.</i></p>

| Version | Change | Problem Solved |
|---|---|---|
| V1 | Reused from previous season | Steering horn broke periodically |
| V2 | Matched base shape; added fillet to steering horn | Sliding during turns; horn breakage |
| V3 | Added curved front bumper | Robot getting stuck against walls in obstacle challenge |

---

## Raspberry Pi 5 Layout and Camera Mount

Slim rotated design with a separated camera tower angled at 35 degrees downward.

### Iterations

**Version 1 — Adapted from Previous Season**
- Layout rotated and made slimmer to reduce footprint and filament.
- Camera positioned high and angled downward.
- Pillars added to replace alignment screws for easier assembly.

**Version 2 — Separated Tower and Improved Camera Angle (Final)**
- Camera angle increased to 35 degrees. Version 1 was not steep enough — background objects outside the game mat were appearing in the frame.
- Camera tower separated from the RP5 layout. Previously any small change to camera angle required reprinting the entire assembly. Separating the two pieces means only the affected part needs to be reprinted.

<p align="center">
  
</p>
<p align="center"><i>Final version of the Raspberry Pi 5 layout with separated camera tower.</i></p>

| Version | Change | Reason |
|---|---|---|
| V1 | Slimmer rotated design; camera high and angled; pillars for alignment | Reduce size and filament; improve camera position |
| V2 | Camera angle increased to 35°; camera tower separated | Remove background objects from frame; reduce reprint time |

---

## Arduino Uno Layout

Main chassis plate holding the Arduino, servo, and front assembly; redesigned for compactness across three versions.

### Iterations

**Version 1 — Adapted from Previous Season**
- Hole locations updated to match Arduino Uno mounting holes.
- Rectangular cutout added in the middle to reduce filament and print time.

**Version 2 — Thicker Base and Added Support**
The frame was shifting and flexing under load:
- Base plate thickness increased to prevent flexing.
- Additional support added around the rectangular cutout to restore rigidity.

**Version 3 — Servo Repositioned for Compactness (Final)**
- Servo moved rearward, shortening the overall robot length.
- Front section extended and reinforced to support bumper attachment.
- Result: more compact robot with servo better positioned relative to the steering linkage.

| Version | Change | Reason |
|---|---|---|
| V1 | Updated hole positions; rectangular cutout | Match Arduino Uno mounting; reduce filament |
| V2 | Thicker base; support around cutout | Frame shifting and flexing under load |
| V3 | Servo moved rearward; front extended for bumper | Reduce robot length; integrate bumper cleanly |

<p align="center">
  
</p>
<p align="center"><i>Final version of the Arduino Uno layout with servo repositioned and bumper support added.</i></p>

---

## Connectors

3D printed C-shaped connectors replacing brass standoffs to speed up assembly and disassembly.

### Why Connectors Instead of Standoffs

Assembling last year's robot took too long due to the number of brass standoffs required. Printed connectors allow the two main chassis layers to be separated and reassembled quickly without tools — useful during competition when time is limited.

### Iterations

**Version 1 — Medium Length**
Medium connector length left adequate space between the Arduino Uno and Raspberry Pi layers while the final robot layout was still being determined.

**Version 2 — Extended Length for Front LiDAR**
Connectors lengthened to accommodate a planned front LiDAR sensor. This idea was later abandoned — the camera proved reliable and straightforward enough to handle all detection tasks on its own.

**Version 3 — Shortened to C-Shape (Final)**
Connectors shortened to make the robot as compact as possible. This caused the battery to no longer fit underneath the Arduino Uno layer. The connectors were redesigned into a C-shape to route around the battery, allowing it to stay in its original position while keeping the chassis layers close together.

| Version | Change | Reason |
|---|---|---|
| V1 | Medium length | Space for layout flexibility during early design |
| V2 | Increased length | Planned front LiDAR — later abandoned |
| V3 | Shortened; C-shape profile | Compact final design; C-shape fixes battery clearance |

<p align="center">
  
</p>
<p align="center"><i>Final version of the connectors layout</i></p>

---

## Differential Gear Design

Our differential gear design went through several iterations, each with its own set of trade-offs and limitations. The table below summarizes the different versions of our differential gear design, along with their design goals, limitations, and takeaways.

| Version | Design Goals | Limitations | Takeaways |
| --- | --- | --- | --- |
| 1 | Adapt a preliminary GrabCAD differential with minor modifications. | The design ignored our size constraints. The teeth did not mesh, wore quickly, and broke at increased speed. | Existing designs must be evaluated against our constraints before testing. |
| 2 | Design the differential from scratch around our size constraints. | Gear wear still caused skipping, rapid direction changes caused locking, and poor meshing generated temperatures exceeding PLA glass transition temperatures. | Material constraints and operating conditions must be considered alongside geometry. |
| 3 | Improve meshing and alignment by adding axles inside the rotating cage and securing all moving components. | The added complexity made tolerance tuning difficult. Friction increased wear, and the design couldn't overcome the surface finish limitations of FDM 3D printing. | A more robust design can introduce new friction, tolerance, and manufacturing problems. |
| 4 | Use a robust metal differential designed for RC cars. | The differential was too large for the universal axles, rubbed against the floor, and bent the rear assembly because of its weight. | Components cannot be viewed in isolation; they are constrained by and must be viewed in the context of the entire system. |
| 5 | Use a compact differential gearbox salvaged from a smaller RC car (1/24–1/28). | The gearbox was salvaged rather than purpose-built. No backups available, and the design is not easily reproducible. | The smaller, lighter, self-contained gearbox eliminated 3D-printed gears, reduced complexity, fit the design constraints, and allowed the robot to run smoothly |

Despite pivoting our design in fundamentally different directions two times, we were able to converge on a final design that met our requirements and constraints. Iteration 1-3 focused on mitigating a fundamental material constraint in FDM PLA, while iteration 4-5 were architectural shifts to completely different models that better meet our requirements. We learned that testing more approaches and iterating quickly near the start of the design process is more effective than premature optimization of a single approach.

<p align="center">
  
</p>
<p align="center"><i>Final version of the differential layout</i></p>

---

## Europe Design

**Mechanical Iterations**
- Turning system V4: front bumper upgraded.
- Arduino layout V4: redesigned around the Arduino Nano, which takes up much less space than the Uno. We added a rack for the Nano to sit on
- Power switch mount V1: dedicated mount added so the switch is held securely instead of loose in the chassis.
- Overall design condensed, making the robot more compact and freeing up internal space.
- Moved the switch to the back of the car

<p align="center">
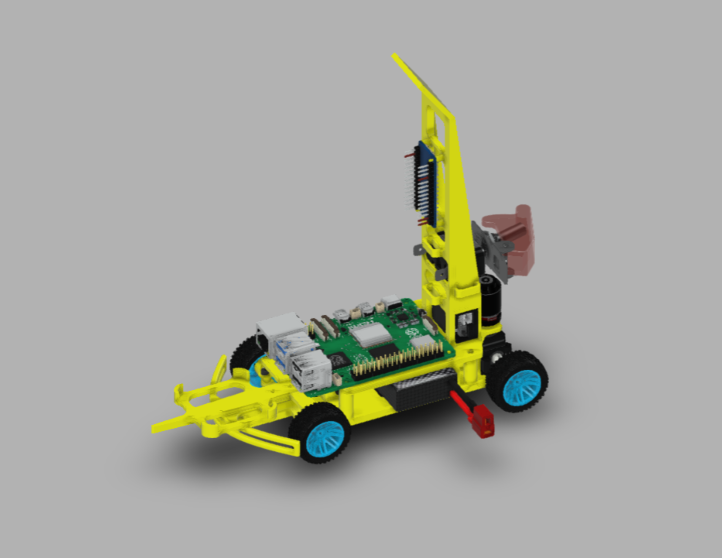
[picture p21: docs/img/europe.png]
  
</p>
<p align="center"><i>Final version of the robot</i></p>

---

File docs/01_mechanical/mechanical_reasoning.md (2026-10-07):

# Mechanical Reasoning

[Back to README](../../README.md)

---

## Size Reasoning

Our robot measures 24 x 10 x 28 cm. The camera is mounted on a tall vertical mast, which provides a significant advantage over the terrain and enhances vertical resolution after perspective transforms are applied.

## Motor Selection

<table>
<tr>
<td width="50%" valign="top" style="border: 1px solid #888; border-radius: 6px; padding: 12px;">

### Generic DC motor

A DC motor is simple, cheap, and easy to control with a basic circuit. It works well for basic speed control but spins unevenly at low speeds, which makes precise movement difficult.

</td>
</tr>
<tr>
<td colspan="2" valign="top" style="border: 1px solid #888; border-radius: 6px; padding: 12px;">

### Furitek Micro Komodo 1212

A small but powerful brushless motor rated at 3450 KV and 120W. It needs a brushless ESC to run but spins smoothly at any speed with no jitter.

</td>
</tr>
</table>

## Motor Choice

The Micro Komodo spins smoothly at all speeds, which is important for our wall-following code to keep the robot at a steady distance from the walls. A regular DC motor would cause the robot to move unevenly at low speeds, leading to unpredictable movement.

<table>
<tr>
<td width="65%" valign="top">

### Potential Improvements
- Experiment with 10 : 58 – 14 : 58 combinations to tune the balance between torque and top speed.
- Upgrade or lubricate bearings to reduce friction and improve consistency over multiple heats.

</td>
<td width="35%" valign="top">

### Performance Specifications
- KV: **3450 rpm/V**  
- No-load @10V: **0.7 A**  
- Power: **120 W**  
- Battery: **2–3S LiPo**  
- Resistance: **0.16 Ω**  
- Max Current: **10 A**  
- Slot/Pole: **12**  
- Shaft: **1.5 × 6 mm**  

</td>
</tr>
</table>

---

## Drive System

**Gear ratio:** 1:4 (motor to wheel)
The WRO Future Engineer rules do not allow differential drive or omnidirectional wheels, Thus narrowing the solution space to effectively 3 options: Rear-Wheel Drive (RWD), Front-Wheel Drive (FWD), and 4-Wheel Drive (4WD). Each of these options has its own advantages and disadvantages, which are summarized in the table below.

| | **RWD** | **FWD** |
| - | --- | --- |
| **Advantages** | Simplest design, fewer parts, lighter weight, better acceleration | Better traction on slippery surfaces |
| **Disadvantages** | Less stable at high speeds, more difficult to control | Prone to skidding, Complex steering mechanism |

We chose RWD because it is the simplest design, which makes it easier to build and maintain. It is also lighter than FWD, which improves acceleration and reduces power consumption. The robot will not be moving at high speeds, so stability is not a major concern. With FWD, the steering mechanism is extremely complex, especially considering that the vast majority of components are designed in-house and 3D printed. The complexity of FWD would make it difficult to design, test, and maintain the robot in a competition environment. We couldn't make a reliable and robust 3D printed differential gear, let alone a complete FWD system. RWD is the best option for our robot because it is the simplest option that satisfies our design constraints (We do not operate at speeds where RWD becomes problematic.) It is also the most reliable option, which is important in a competition environment.

## Steering System

- **Steering type:** Parallel (Zero-Ackermann)
- **Actuator used:** Hitec HS-5055MG servo motor
- **Steering linkage:** Servo-actuated rack and pinion, moving both front wheels through a shared tie rod so they turn to the same angle rather than the different angles a true Ackermann linkage would use
- **Steering range:** 30-150 degrees (90 is straight), limited by rack travel and chassis clearance, not by the servo's own 0-180 degree range
- **Why selected:**
    - A servo gives direct, repeatable position control, the steering angle the PD controller calculates each frame can be commanded and held without extra feedback hardware, unlike a plain DC motor.
    - Rack and pinion is simple to 3D print and assemble reliably compared to a multi-link Ackermann setup, and converts the servo's rotational output into linear rack travel directly.
    - True Ackermann geometry only pays off at speeds where the inner/outer wheel angle difference meaningfully reduces tire scrub. At the robot's operating speed of 1.5-2.0 m/s (see [torque_speed_reasoning.md](./torque_speed_reasoning.md)), that difference doesn't matter enough to justify the added linkage complexity.

### Wheel Placement

We placed the front and rear axles as close together as the chassis allows. The wheels sit
right up against the battery and steering servo without touching either one.

A shorter wheelbase gives the car a smaller turning radius at the same steering angle. That
lets it take the corners of the Open Challenge track tighter, and it leaves more room to steer
around traffic-sign pillars in the Obstacle Challenge.

---

## Servo Motor

We selected a standard servo motor for steering because it provides precise and repeatable control of the front wheels. Unlike a motor that would need additional position feedback and a more complicated control system, a servo can move directly to a commanded angle and hold that position. This makes it easier for the robot to follow the steering angles calculated by our control code and helps it make consistent turns.

A servo motor also fits well with our focus on simplicity and reliability. Its compact size and straightforward interface make it easy to mount and connect to the robot's control system, while its position control reduces the risk of over or under-steering. Reliable steering is especially important in a competition environment, where small errors in each turn can accumulate and cause the robot to leave the intended path.

### HS-5055MG 11.9g Metal Gear Digital Micro Servo

- **Operating Voltage:** 4.8V – 6.0V DC
- **Max Torque:** 22 oz/in (1.6 kg/cm)
- **Speed:** 0.17s/60° @ 6.0V
- **Stall Current:** 700 mA
- **Gear Material:** Metal
- **Weight:** 9.5 g
- **Circuit Type:** G1 Programmable Digital

**Where to Buy:** [Click Here](https://hitecrcd.com/hs-5055mg-economy-metal-gear-feather-servo/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)

### Potential Improvements
- Improve response time. This servo motor is not as quick as higher-end micro servos, which reduces steering precision during sharp turns.
- Upgrade to a higher-torque digital micro servo for more reliable steering.

This servo motor was chosen for its compact size, strong torque, and durable metal gears, making it great for precise steering control.

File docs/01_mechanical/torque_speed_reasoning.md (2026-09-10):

# Torque and Speed Reasoning

[Back to README](../../README.md)

---

## Hardware Used

- **Motor:** Furitek Micro Komodo 1212 brushless motor, 3450 KV
- **Voltage:** 7.4V (2S LiPo)
- **Wheel diameter:** 35mm
- **Gear ratio:** 1:4 (motor to wheel)
- **Vehicle mass:** 467g

---

## Calculations

**No-load motor RPM at 7.4V:**
```
RPM = KV × Voltage = 3450 × 7.4 = 25,530 RPM
*While max power*
```

**Wheel RPM after gear reduction:**
```
Wheel RPM = 25,530 ÷ 4 = 6,383 RPM
*While max power*
```

**Linear speed at wheel:**
```
Wheel circumference = π × 35mm = 110mm = 0.11m
Speed = 6,383 RPM × 0.11m ÷ 60 = ~11.7 m/s (theoretical no-load max)
```

In practice, the robot runs at 30–40% throttle in software, giving an effective competition speed of approximately **1.5–2.0 m/s**, which is well within the camera's ability to process frames and react.

---

## Design Reasoning

- **Why this motor was selected:** The Micro Komodo 1212 is compact and lightweight at 17.5g while delivering 120W of power. It spins smoothly at all speeds with no cogging, which is critical for consistent wall-following behavior. See [Motor Selection](./mechanical_reasoning.md#motor-selection) for the full comparison.
- **Why this wheel size was selected:** 35mm wheels were chosen after the purchased off-the-shelf differential was found to sit too low. The 35mm diameter raised the chassis enough to give the differential adequate ground clearance without requiring a full redesign of the chassis geometry.
- **Why this speed range is suitable:** The robot needs to react to walls and obstacles within the time it takes to travel one camera frame's worth of distance. At 2.0 m/s and 62.5 fps, the robot travels approximately 3.2 cm per frame, fast enough to complete laps in time but slow enough for the vision pipeline to detect and react to corners and pillars reliably.
- **Why this torque level is suitable:** The 1:4 gear ratio multiplies the motor's torque by 4 at the wheel, providing enough force to accelerate the 467g chassis from a stop and maintain speed through corners. The ratio was selected to balance torque and top speed, a higher ratio would reduce top speed unnecessarily, and a lower ratio would reduce low-speed torque.

---

## Trade-Offs

- **Higher speed advantages:** Faster lap times; more time to react during the run if something goes wrong.
- **Higher speed disadvantages:** Less time per camera frame to detect corners and pillars; more aggressive PD corrections needed; increased risk of crashing into walls during sharp turns.
- **Higher torque advantages:** Better acceleration from stops; more reliable movement on imperfect surfaces; less likely to stall mid-turn.
- **Higher torque disadvantages:** Requires a higher gear ratio which reduces top speed; increased stress on the 3D printed differential gears.

---

## Testing Evidence

| Test | Configuration | Observation | Conclusion |
|---|---|---|---|
| Motor torque under load | New differential gearbox, 7.4V | Motor spinning but robot unable to move after sharp turns | Possible gearbox friction or gear slipping under load |
| Speed at 30% throttle | 35mm wheels, 1:4 ratio, 7.4V | Robot moves at controllable speed suitable for wall following | 30–40% throttle is the appropriate operating range |
| 3D printed differential durability | 3D printed differential, various speeds | Differential broke too often under normal use | Switched to pre-built differential gearbox |
| ESC calibration | Furitek Lizard Pro | Uncalibrated ESC caused loss of torque at expected throttle values | ESC must be calibrated to match code's PWM pulse range |

---

## Final Decision

The Furitek Micro Komodo 1212 at 7.4V with a 1:4 gear ratio and 35mm wheels gives a theoretical top speed of ~11.7 m/s, but the robot is intentionally limited to 30–40% throttle in software for a competition speed of approximately 1.5–2.0 m/s. This range keeps the robot within the reaction capability of the 62.5 fps vision pipeline while providing enough torque through the gear reduction to move the 467g chassis reliably through corners. The 35mm wheel size was also a practical fix for ground clearance issues introduced by the off-the-shelf differential.

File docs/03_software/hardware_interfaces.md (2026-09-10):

# Hardware Interface Details

[Back to Software Overview](../../README.md)

---

## Camera

The [`AsyncCamera`](https://apostla-api-reference.web.app/interface.html#piclient.core.interface.AsyncCamera) runs in its own process using the Raspberry Pi `picamera2` library. Since `picamera2` is a blocking library, captures are run on a thread pool so the async event loop stays responsive.

Each frame is written directly into shared memory using a zero-copy method (`np.copyto`). The vision process reads from the same shared memory block without any additional copying. A pipe signal tells the vision process when a new frame is ready.

**Config options:** resolution, format, and frame rate are all set in `piclient.toml` under `[CameraConfig]`.

---

## Arduino Client

The Arduino is connected over USB serial. The [`Client`](https://apostla-api-reference.web.app/interface.html#piclient.core.interface.Client) sends text commands and receives responses asynchronously.

Each command is assigned a transaction ID (TID). A background listener reads every response line and matches it to the correct pending command by TID. This means multiple commands can be sent without waiting for a response first.

**Main commands:**

| Command | What it does |
| --- | --- |
| [`verify_connection()`](https://apostla-api-reference.web.app/interface.html#piclient.core.interface.Client.verify_connection) | PING/PONG handshake to confirm the Arduino is connected |
| [`set_servo_angle()`](https://apostla-api-reference.web.app/interface.html#piclient.core.interface.Client.set_servo_angle) | Sets steering angle (clamped 0–180°) |
| [`set_motor_speed()`](https://apostla-api-reference.web.app/interface.html#piclient.core.interface.Client.set_motor_speed) | Sets drive speed (normalized −1 to 1) |
| [`drive_motors()`](https://apostla-api-reference.web.app/interface.html#piclient.core.interface.Client.drive_motors) | Sets both speed and angle at the same time |

**Back-pressure handling:** If the Arduino replies with `WAITMS <ms>`, the client waits the requested time before retrying. This prevents the Pi from overwhelming the Arduino.

The serial port is set in `piclient.toml` under `[ClientConfig]`.

---

## [`DriveCommandExecutor`](https://apostla-api-reference.web.app/interface.html#piclient.core.interface.DriveCommandExecutor)

The [`DriveCommandExecutor`](https://apostla-api-reference.web.app/interface.html#piclient.core.interface.DriveCommandExecutor) sits between the fast control loop and the slower serial link. The control loop can call [`submit()`](https://apostla-api-reference.web.app/interface.html#piclient.core.interface.DriveCommandExecutor.submit) every frame without ever waiting for the Arduino to respond.

Internally, the executor stores only the latest command. A single background worker sends it to the Arduino when the serial link is free. If a new command arrives before the old one is sent, the old one is overwritten. Stale commands are never sent.

This is what allows the control loop to run at full frame rate without stalling on serial latency.

--- 

[Interface - Apostla 0.0.1 documentation](https://apostla-api-reference.web.app/interface.html)

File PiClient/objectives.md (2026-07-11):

# Goals

> *Crossed out words mean objective completed*

## Electrical Objectives

- Make schematic for the robot, because apprently PCBs take months to ship and it ain't coming. So make the schematic for the raw wiring and then just solder it together on a perfboard or something.
- Integrate LiDAR into the electronics.

## Coding Objectives

- ~~"When you feel like you need reliability SLAs for a three man team working on a high school robotics project, you have already lost." - Me, March 26, 2026.~~
- ~~Integrate sphinx and write docstrings for all modules, also group it into private and public APIs. Spend uh... way too much time on frontend aesthetics and making a beautiful documentation website that no one will read.~~
- Make LiDAR work :hmmyes:
- ~~Refactor all modules in src_min to drop async and multiprocessing and multithreading, and instead use a single-threaded, synchronous design.~~
- ~~KISS, discard two months of work because I am a fucking idiot that overengineered everything and can't stop myself from doing it.~~

## Mechanical Objectives

List of things to improve but not big enough to print a new part for:

> ~~- Add a place to screw in voltage regulator~~  
> ~~- Make camera angle more downwards~~  
> ~~- Create a Lidar holder + make space for it~~  
> ~~- Fix differential gear issue~~
> - Create a spot to put switch

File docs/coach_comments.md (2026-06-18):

# April 8th
```
I agree with Michael that you can overlapping image grabbing and image processing to increase the overall throughput. For example, while you're processing frame N, the camera hardware can be capturing frame N+1. By the time processing finishes, the next frame is already ready. The decision really depends on what frame rate you need. For Open Challenge wall following, 30fps is likely plenty. Even with sequential capture + processing, we can keep up with the full 30 fps. But if you're doing Obstacle Challenge and need fast reaction to pillars/parking lots, larger fps (e.g. 60) with overlapped capture/processing could make a real difference.
Example #1: 30fps Open Challenge
Frame interval: 33ms. Assume capture takes 15ms. Processing takes 15ms.
Sequential: 15 + 15 = 30ms. That's under 33ms, so you finish and wait 3ms idle for the next frame. Your effective rate is 30fps — the camera is the bottleneck, not your code.
Overlapped: ~15ms per cycle. But you still can't get a new frame faster than every 33ms. So you finish in 15ms and wait 18ms idle. Still 30fps.
Either way you get 30fps. Overlapping just increases your idle time. It doesn't help.
Example #2: 60fps Obstacle Challenge
Frame interval: 16.7ms. Assume capture takes 15ms. Processing takes 15ms.
Sequential: 15 + 15 = 30ms. That exceeds 16.7ms, so you can only process one frame every 30ms, dropping your effective rate to ~33fps (1000/30) instead of 60fps. You're processing every second frame while one goes to waste in between.
Overlapped: While processing frame N (15ms), frame N+1 is being captured simultaneously. Processing finishes in 15ms, which is under 16.7ms, so the next frame is ready. You keep up with the full 60fps.
The rule:
Overlapping only matters when capture + processing > frame interval. At 30fps (33ms interval), 15+15=30 fits. At 60fps (16.7ms interval), 15+15=30 doesn't fit — that's when overlapping saves you.
```
# April 11th

```
 1) The architecture is significantly over-engineered for open challenge.
 This codebase uses async/await, multiprocessing with shared memory, inter-process pipes, thread pool executors, a transaction-ID-based serial protocol, and structured logging — all for a robot that needs to follow walls and turn corners. While the engineering is impressive, the complexity introduces many failure points and makes debugging on competition day very difficult. It is like shooting a fly with a missile.

 __init__.py — Entry point. Parses command-line args (debug/verbose/test modes), configures logging with loguru, and calls asyncio.run(run()) to start the robot.
 asyncCamera.py — Wraps PiCamera2 in an async context manager. Captures YUV420 frames, crops the top ROI, upscales the UV planes, and writes the result into shared memory for other processes to read.
 commProtocol.py — Async serial client for Arduino communication. Each command gets a transaction ID, and a background listener matches responses to pending requests. Exposes high-level methods like set_servo_angle, set_motor_speed, and drive_motors.
 controller.py — A simple PD controller class. Takes an error, returns a correction value using proportional and derivative terms.
 open_challenge.py— The main control loop. Launches camera and vision as separate processes, then runs a two-state machine ("Follow wall" / "Turn") that reads vision data and sends drive commands. 
 visionProcessing.py— All computer vision logic. Detects walls (black), obstacles (green/red), corner lines (orange/blue), and field boundaries (white) using color thresholding in YUV space. Computes distances and centroids. The async subclass wraps everything in executor threads for use with multiprocessing.

 In principle, don't pay for complexity until you need what it buys!
 You have limited debugging time, the robot needs to work on competition day, and the team members need to understand every line of code.
 A solution that every team member can read, debug, and modify under pressure beats an elegant but complex one.

 Here's what I'd suggest: keep the multi-file structure but drop the async/multiprocessing complexity.
 The Raspberry Pi is processing one camera frame at a time in a sequential loop — there's no real concurrency benefit here since everything depends on the latest frame.
 The only thing you could possibly gain using "async" is you could start capturing the next frame while sending the serial command - but that's negligible compared to the simplicity you gain.

 Suggested structure:
 main.py              # Entry point, main loop, state machine
 camera.py            # Camera init and frame capture (thin wrapper)
 vision.py            # Color detection, wall areas, line detection
 comm.py              # Serial communication with Arduino
 controller.py        # PD controller (already good as-is)
 config.py            # All tunable constants in one place

 Each module is a plain synchronous class or set of functions. No async, no multiprocessing, no shared memory, no thread pools. The main loop calls them in sequence.

```

# April 15th

```
1) Color Space — YUV 
Working in native YUV420 avoids a cvtColor call every frame. Thus make image processing faster.
Color detection thresholds use only U and V channels (frame[:, :, 1:3]), which correctly ignores brightness.
However, UV thresholds might be less intuitive to re-tune at competition, where lighting condition is different.

Suggestion: 
LAB is most robust under different lighting conditions.
Have a fallback plan of LAB space.

2) Camera.py
Many hardcoded numbers: 512*384, 256*192, and INITIAL_ROI = 100. 
Suggestion: Put them in config.py

3) controller.py
Suggestion: reset previous_error to 0 when switching states

4) visionProcessing.py
Suggestion: No need to process RED and Green for open challenge

5) State transition
Corner lines appear → enter Turn. Corner lines disappear → back to Follow wall. That's it — purely based on whether orange/blue lines are detected in the current frame.
It doesn't explicitly decide "turn left" or "turn right." It chases the largest corner line's centroid, steering to keep it at the frame center (192 pixels). 
The sign of x_centroid - 192 determines the steering direction — line to the left of center gives negative correction, line to the right gives positive correction.

Potential issues
Corner line color is ignored. Orange means CW, blue means CCW. The code doesn't check corner_lines[0].color at all. 
It just follows wherever the line happens to appear in the frame. This could work accidentally if the line position correlates with the correct turn direction, but it's not reliable.

The exit condition is too early. The robot switches back to "Follow wall" the moment corner lines leave the frame. 
But the line might disappear while the robot is still mid-turn — it hasn't completed 90° yet, and the walls haven't reappeared. 
The robot returns to wall following without walls visible, gets inf distances, and produces garbage output.

The entry condition can be too late. If the camera doesn't detect corner lines reliably (lighting, threshold issues), 
the robot stays in "Follow wall" while entering a corner. One wall disappears, wall_x_diffs goes to inf, and the PD controller breaks.

Single-frame detection is fragile. A momentary false positive (noise detected as a corner line) flips the state to Turn. 
A momentary false negative (corner line missed for one frame) flips it back to Follow wall mid-corner. There's no hysteresis or confirmation — one frame decides the state.

Suggestion:
Enter Turn when corner lines appear or one wall disappears
Use the corner line color to set a fixed turn direction
Stay in Turn until both walls are visible again, not until corner lines disappear
Require several consecutive frames before switching states, to filter noise

6) No lap counting
The robot runs forever — there's no counter tracking corner lines to stop after 3 laps (12 corners).

7) inf wall distances break the PD controller. 
get_wall_distance returns float("inf") when a wall isn't detected, and the PD controller computes inf - inf = NaN or inf - number = inf. 
This will produce garbage steering commands even in "Follow wall" state if a wall is momentarily missed. It needs an explicit guard.

8) Same speed in both states.
Suggestion: User slower speed for corner turn

9) aioserial imported but used synchronously. 
The code calls self.SERIAL.write() and self.SERIAL.readline() — the sync methods. Regular pyserial would be simpler and avoids an unnecessary dependency.

10) A perspective transform converts the camera's angled view into a bird's-eye (top-down) view.
src = np.array([
    [0, 0],
    [0, 0],
    [0, 0],
    [0, 0],
], dtype=np.float32)
dst = np.array([
    [0, 0],
    [0, 0],
    [0, 0],
    [0, 0],
], dtype=np.float32)

This is placeholder code that needs to be filled in with real calibration values.

The question is whether it's needed. It takes time to calibrate in a new environment.
For Open Challenge, wall following just needs to know "am I closer to the left wall or the right wall?" 
Bounding box positions in the raw camera view answer that fine — perspective distortion doesn't change which wall is closer. 
The distances won't be proportional to real centimeters, but the PD controller doesn't care about absolute distance, only the relative error between left and right.

Suggestion: bypass perspective transform for Open Challenge
```

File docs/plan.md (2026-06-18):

# Plan
## 2026-02-05
~~First Commit~~

## 2026-03-05
### Finish Robot Chassis - Elvis
1. ~~Finish differential gear~~
2. ~~Finish implementing last years turning system~~
3. ~~Map out layout of where everything should go~~
4. Design a way to hold everything together
5. Assemble everything

### Finish custom PCB - Michael
1. ~~Validate schematic.~~
2. ~~Finish footprint placement in board editor.~~
3. ~~Send order to the FAB and run physical tests.~~

## 2026-04-05
### Open Challenge Completed - Michael, Elvis
1. Create `VisionTuning.py`, a GUI that takes a video file or live frames and provides easy tuning for color ranges.
2. Finish Unittests
    - ~~`camera.py`, validating asynchronous wrapper for the `PiCamera2` Library found in `AsyncCamera.py`.~~
    - ~~`RPC.py`, testing the asynchronous two-way Remote Procedure Call between the Raspberry Pi 5 and Arduino.~~
    - `Vision.py`, A vision processing test that integrates `AsyncCamera` and `AsyncVisionProcessor`, utilizing multiprocessing and shared memory.
    - `turning.py`, integrating sensors to corner.
3. Develop main file `OpenChallenge.py`.
4. Run integration tests and tune `OpenChallenge.py`.

### Documentation - Ryan
1. Create design journal and document engineering process.
2. Justify design and show compatibility tests.
3. Full API reference for `asyncCamera`, `commProtocol`, `controller` and `visionProcessing` modules.

## 2026-05-05
## 2026-06-05
## 2026-07-05
## 2026-08-05
### Finish Obstacle Challenge - Michael, Elvis
1. Run Unittests
    - `obstacleDetection.py`, validating obstacle detection and location.
    - `obstaclePlanning.py`, generating a cubic fit-point spline between obstacle avoidable nodes.
    - `obstacleAvoidance.py`, testing obstacle avoidance in a straight line.
    - `Parking.py`, integrating LiDAR and camera data to parallel park effectively.
2. Develop main file `ObstacleChallenge.py`
3. Run integration tests and tune `ObstacleChallenge.py`.

### Documentation - Ryan
1. Update design journal and document engineering process.
2. Justify design and show compatibility tests.
3. Full API reference for `obstacleDetection`, `obstaclePlanning`, `obstacleAvoidance` and `parking` modules.
4. Live deployment of documentation on GitHub Pages.
## 2026-08-19
### Optimize Logic for Real-Time Speed - Michael, Elvis
1. Observe real-life behavior of the robot and identify potential improvements.
2. Refactor logical elements for maximal real-world speed, such as optimizing the path planning algorithm and reducing center of mass for better turning.
3. Comprehensively profile code and identify runtime bottlenecks.

## 2026-09-05
### Optimize Code for Runtime - Michael, Elvis
1. Optimize code to reduce runtime, such as utilizing more efficient data structures and algorithms, and leveraging hardware acceleration where possible.
2. Run comprehensive tests to ensure that optimizations do not introduce bugs or regressions.

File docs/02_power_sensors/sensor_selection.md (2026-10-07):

# Sensor Selection

[Back to README](../../README.md)

This document explains which sensors were selected for the robot, why they were chosen, and what alternatives were considered.

---

## Sensing Requirements

The robot needs to:

- Detect walls and stay centered between them
- Identify colored pillars (red and green) and pass on the correct side
- Detect corner lines to know when to turn
- Count laps to know when to stop
- Detect the parking lot for the obstacle challenge

---

## Sensor Summary

Our robot only uses a single sensor: An OV5647 camera with a wide angle lens. The camera is mounted on the front of the robot, facing forward, and captures frames at 640x480 resolution at up to 62.50 fps. The camera is the only data source for our system, and it is used for all sensing tasks. The camera's raw BGR arrays are first converted to HSV color space, then fed to downstream pipelines for object detection.

We selected the OV5647 camera because it is the only sensor that can detect color, which is required for both the obstacle challenge (pillar colors) and the open challenge (corner line colors). The camera is also compact, lightweight, and fully supported by the `picamera2` library on Raspberry Pi OS (64-bit) Bookworm or later. The camera is elevated above the robot's body to give it a clear view of the track and obstacles. We also have an IMU which combines a gyroscope, which measures how fast the robot is rotating, and an accelerometer, which measures acceleration and tilt. 

We considered adding a 2D LiDAR sensor, which can offer precise distance measurements, but introduces serial/I2C communication latency, extra CPU overhead for multi-sensor synchronization, and additional mass. Since monocular vision boundary tracking meets our positional accuracy requirements within our 62.5 FPS loop, adding distance sensors introduced unnecessary architectural complexity.

We also considered using the Pi Camera Module 3 Wide, which supports higher frame rates and resolutions, but is significantly more expensive and was not necessary for our current design. The OV5647 camera provides adequate performance for our needs at a lower cost. While the current camera is a performance bottleneck, our system does not operate at speeds where the frequency of the control loop is a limiting factor. Despite operating at the camera's maximum frame rate of 62.50 fps, the robot can still navigate the track effectively at the speeds required for the competition.

---

## Camera — OV5647

**Purpose:** The camera is the primary sensor for detecting everything color-dependent — colored pillars (red and green), corner lines (orange and blue), and walls (black).

**What it provides:** Raw image frames at 640x480 up to 62.50 fps, processed in HSV color space to detect objects by color and shape.

**Why it was selected:**

- The camera can distinguish colors, which is essential for both challenges
- CSI-2 interface provides lower latency than USB cameras
- Good support by the `picamera2` library on Raspberry Pi OS (64-bit) Bookworm or later
- Lightweight and compact

**Advantages:**

- Can detect multiple instances of different object types in a single frame
- No external power required beyond the Pi's CSI port
- Fine-grained control over resolution, frame rate, exposure, and other camera settings through `picamera2`
- Easy to process data with mature scientific Python libraries like OpenCV and NumPy

**Limitations:**

- Performance degrades under poor or inconsistent lighting
- Requires HSV threshold tuning under competition lighting conditions
- Cannot measure distance directly; Distance must be inferred from pixel counts or object sizes, which is less reliable than direct distance measurements

**Alternatives considered:**

- **USB webcam** — higher latency due to USB overhead, more bandwidth contention with Arduino
- **Pi Camera Module 3 Wide** — supports 120 fps at higher resolution, but significantly more expensive; considered as a future upgrade

---

## Trade-Offs

| Trade-Off | Decision |
| --- | --- |
| Cost vs performance | OV5647 chosen over Pi Camera Module 3, adequate performance at lower cost |
| Throughput vs Accuracy | Camera capped at 62.50 fps at 640x480, higher resolution reduces frame rate below what the control loop needs |
| Redundancy vs complexity | Single camera chosen, simplifies design and reduces weight, cost, and complexity |

---

## Final Decision

The OV5647 camera covers all sensing requirements for the competition. The camera is a lightweight, compact, and cost-effective solution that provides sufficient performance for both the open and obstacle challenges. While there are trade-offs in terms of accuracy and redundancy, the single-sensor approach simplifies the design and reduces potential points of failure.

---

## IMU 

**Purpose:** Measures the robot's rotation so it always knows which direction it is facing (its heading). The IMU is built into the Arduino Nano, and the Nano sends the heading to the Raspberry Pi over USB serial.

**What it does:**
An IMU combines a gyroscope, which measures how fast the robot is rotating, and an accelerometer, which measures acceleration and tilt. By adding up the gyroscope's rotation readings over time, the Nano calculates the robot's heading in degrees relative to its starting direction. 

---

## Arduino Nano 

**Purpose:** Low-level hardware controller that handles PWM output to the ESC and servo, reads heading data from its built-in IMU, and exchanges commands and sensor data with the Raspberry Pi over USB serial.

**Why it was selected:**
The Raspberry Pi 5 runs Linux, which is not a real-time operating system. It cannot guarantee microsecond-level PWM timing under load. When the vision pipeline and control loop are running at 62.5 fps, the CPU is busy enough that GPIO-based PWM timing becomes unreliable. A dedicated microcontroller produces PWM in hardware, guaranteeing consistent pulse widths to the ESC and servo regardless of what the Pi is doing.

**Why we switched from the Arduino Uno R3:**
- **Size:** The Nano is a fraction of the Uno's footprint. Switching let us condense the whole robot layout and free up internal space (see Arduino Layout V4 in Mechanical Iterations).
- **Built-in IMU:** The Nano has an onboard IMU, which gives the robot a heading reading without adding a separate sensor or extra wiring. Heading data can support turn detection and lap counting alongside vision.
- **Same role, same interface:** The Nano still connects to the Pi over USB serial, so the Pi-side communication code needed only minor changes.

**Advantages:**
- Guarantees precise PWM timing independent of Pi CPU load
- Onboard IMU provides heading data with no extra hardware
- Much smaller footprint than the Uno
- Simple USB serial connection to the Pi
- Easy to flash and modify via PlatformIO

**Limitations:**
- Adds a serial communication step between the control loop and the hardware, introducing a small amount of latency
- Requires a separate USB cable and port on the Pi
- Some Uno code did not port directly. For example, `Serial.printf` with `%f` did not print floats correctly on the Nano and had to be replaced with `Serial.print` (see Week 41)

**Alternatives considered:**
- **Arduino Uno R3 (used earlier this season)**: reliable, but too large for the condensed layout and has no onboard IMU
- **Direct Pi GPIO PWM**: unreliable under Linux without a dedicated real-time co-processor
- **ESP32**: more capable but significantly more complex to set up; overkill for this application
- **Hiwonder controller (used last year)**: replaced for simpler software control and better documentation

---

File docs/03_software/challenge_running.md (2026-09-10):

# Challenge Runner Details

[Back to Software Overview](../../README.md)

---

## Overview

When you run `wro`, it loads the [`Config`](https://apostla-api-reference.web.app/lib.html#piclient.core.lib.Config), connects to the Arduino through [`Client`](https://apostla-api-reference.web.app/interface.html#piclient.core.interface.Client), starts the camera, vision, and recorder processes, and enters the main control loop. The loop runs once per fresh vision result.

Each loop iteration:

1. Gets the latest wall, obstacle, and parking lot data from the vision process
2. Runs it through the [`PD`](https://apostla-api-reference.web.app/lib.html#piclient.core.lib.PD) controller to calculate a steering correction
3. Checks the [`StateMachine`](https://apostla-api-reference.web.app/lib.html#piclient.core.lib.StateMachine) to decide what to do
4. Submits a drive command to the [`DriveCommandExecutor`](https://apostla-api-reference.web.app/interface.html#piclient.core.interface.DriveCommandExecutor)

---

## Open Challenge

### State Machine

| State | What triggers it | What the robot does |
| ----- | --- | --- |
| Straight | Default | Wall follow using [`PD`](https://apostla-api-reference.web.app/lib.html#piclient.core.lib.PD) controller |
| Turn | Black fill in center ROI confirmed over several frames | Switch to more aggressive PD gains |
| Final Turn | Last turn of the last lap | Same as Turn |
| Final Straight | After the final turn | Drive to stop position |

### Corner Detection

Corners are not triggered on a single frame. The center ROI must fill up with black pixels for [several consecutive frames](https://apostla-api-reference.web.app/lib.html#piclient.core.lib.Config.SharedChallengeConfig) before a turn is triggered. This filters out noise and false detections from shadows or lighting changes.

### Lap Counting

The robot counts completed turns to track laps. The number of turns per lap is set in `piclient.toml` under `[OpenChallengeConfig]` as `LAP_LENGTH_IN_TURNS`. After the required number of turns, the robot begins the shutdown sequence.

### [`PD`](https://apostla-api-reference.web.app/lib.html#piclient.core.lib.PD) Controller

The steering correction is calculated as:

```python
error = right_wall_distance - left_wall_distance
correction = Kp * error + Kd * (error - previous_error)
servo_angle = correction * 90 + 90
```

Gains `Kp` and `Kd` are set separately for wall following and corner turning in `piclient.toml`.

---

## How Vision and the State Machine Work Together

The vision process and the state machine run as separate processes but are tightly coupled through a pipe. Every camera frame produces a set of measurements — wall distances, pillar positions, corner fill — and these measurements are what the state machine acts on.

The key relationship is:

- **Vision tells the state machine what it sees.** It does not make decisions — it only reports numbers.
- **The state machine decides what to do with those numbers.** It evaluates the measurements against thresholds, applies hysteresis, and chooses a state.
- **The state determines which drive command gets sent.** Different states use different PD gains and speeds.
This separation means the vision code can be tested independently using a recorded video, and the state machine logic can be reasoned about without worrying about how the measurements were produced.

---

## How HSV Detection Works

The camera captures frames in BGR format. Before any detection is done, each frame is converted to HSV (Hue, Saturation, Value) color space. HSV separates color information from brightness, which makes detection more stable under different lighting conditions — a red pillar in shadow still has roughly the same hue and saturation, only its value changes. We swap the B and R channels to avoid maintaining two thresholds for red, since red wraps around the hue wheel at both 0° and 180°. The OpenCV `inRange` function is used to create binary masks for each color of interest.
**Walls** are detected by masking for black pixels — low value, low saturation. The amount of black in the left, right, and center regions of the frame is counted and used as a proxy for wall distance.
**Pillars** are detected by masking for red and green:

- **Green** sits around hue 40–80 in OpenCV's 0–180 scale. A single mask covers the full green range.
- **Red** is swapped to the blue channel, so it sits around hue 0–20. A single mask covers the full red range.

```python
mask_green = cv2.inRange(hsv, lower_green, upper_green)
mask_red = cv2.inRange(hsv, lower_red, upper_red)
```

Once masked, contours are found and the largest one is taken as the detected pillar. The position of that contour relative to the nearby wall determines the steering target.

All HSV threshold values are set in `piclient.toml` under `[VisionConfig]` and should be tuned under competition lighting before each run.

---

## Obstacle Challenge

### [`StateMachine`](https://apostla-api-reference.web.app/lib.html#piclient.core.lib.StateMachine)

Introduces `obstacle_avoid` and `parallel_parking` states.

| State | What triggers it | What the robot does |
| ----- | --- | --- |
| Straight | Default | Wall follow using [`PD`](https://apostla-api-reference.web.app/lib.html#piclient.core.lib.PD) controller |
| Turn | Corner detected | Hard steer toward missing wall |
| Obstacle Avoid | Vision returns a pillar target | Steers toward the gap between pillar and wall |
| Parallel Parking | Vision returns a parking lot target and the 3rd lap is complete | Steers toward the parking lot and executes a parallel parking maneuver |

### Obstacle Avoidance

When the [`ObstacleChallengeVisionProcessor`](https://apostla-api-reference.web.app/vision.html#piclient.core.vision.ObstacleChallengeVisionProcessor) detects a pillar, it returns a target point — a dynamic, proximity-based, offset from the obstacle towards the relevant wall. The control loop steers toward this target using a separate [`PD`](https://apostla-api-reference.web.app/lib.html#piclient.core.lib.PD) controller with gains set in `piclient.toml` under `[ObstacleChallengeConfig]`.

Obstacle avoidance takes priority over wall following. Once the pillar clears the frame, the robot returns to normal wall following.

**WRO rule:** Green pillars are passed on the left. Red pillars are passed on the right.

---

## Shutdown

When the run ends the robot:

1. Stops the motors
2. Centers the steering
3. Terminates the camera and vision processes
4. Releases and unlinks the shared memory block

---

[Open Challenge - Apostla 0.0.1 documentation](https://apostla-api-reference.web.app/open_challenge.html)

[Obstacle Challenge - Apostla 0.0.1 documentation](https://apostla-api-reference.web.app/obstacle_challenge.html)

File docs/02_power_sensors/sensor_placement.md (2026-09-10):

# Sensor Placement

[Back to README](../../README.md)

---

## Camera

The camera is mounted 19 cm from the floor and angled downward.

**Why angled downward:**
Pointing the camera downward removes anything outside the game mat from the frame that would otherwise interfere with the HSV color detection. Without the downward tilt, the top portion of the frame picks up irrelevant colors that can trigger false detections.

**Why 19 cm:**
The height is a tradeoff between two things, the further up the camera is, the larger the field of view and the more of the track it can see ahead, which helps with early corner and pillar detection. However, a taller sensor tower takes longer to print and is more likely to tip or vibrate during sharp turns. 19 cm was chosen as a balance between a useful field of view and a practical, stable mount height.

## LiDAR
We were thinking about using a LiDAR but we scrapped that idea because we didn't have enough time and the robot was fine without it.

It was going to be placed in the front of our robot at a medium height so it could detect objects like the parking lot without covering up the camera.

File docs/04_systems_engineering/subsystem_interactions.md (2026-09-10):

# Subsystem Interactions

When engineering a complex robot, it is not enough to design each subsystem independently. The mechanical, electrical, sensing, software, and control systems must work together as one system. A change in one subsystem can change the requirements for several others, so we use the interfaces between subsystems to reason about the complete robot.

We make our interfaces explicit throughout our [codebase](https://apostla-api-reference.web.app/_modules/piclient/core/vision/data.html) and documentation. Each subsystem has a clear purpose, and the inputs and outputs are well-defined. This gives us some flexibility to change the internal implementation of a subsystem without affecting the rest of the system, as long as the interface remains consistent. It also allows us to reason about the interactions between subsystems and identify potential issues before they arise.

## System Overview

The robot is a rear-wheel-drive vehicle with front servo steering. An OV5647 camera provides the main environmental input to a Raspberry Pi 5. The Raspberry Pi processes the camera frames, selects the current challenge behavior, and sends drive commands to an Arduino Uno over USB serial. The Arduino generates the PWM signals for the ESC and steering servo.

The main interaction chain is:

1. **Power system** supplies the motor, ESC, servo, Raspberry Pi, camera, and Arduino.
2. **Camera and mounting system** provide images with a field of view that includes the walls and colored pillars.
3. **Vision system** converts each image into wall, corner, and obstacle measurements.
4. **State machine and controller** select the current maneuver and calculate the steering and speed command.
5. **Serial communication system** transfers the latest command to the Arduino without blocking the control loop.
6. **Arduino and drivetrain** turn the command into physical motion, which changes the next camera image.

This forms a feedback loop: the robot moves, the camera observes the new position, and the controller corrects the next movement.

## Subsystem Interface Map

| Subsystem | Provides | Depends on | Main interaction |
| --- | --- | --- | --- |
| Chassis and drivetrain | Motion, traction, steering response | Battery power, ESC, servo commands | Converts control output into robot position and velocity |
| Power system | Battery and regulated voltage rails | Battery, regulator, wiring | Supplies stable power while limiting voltage drop and noise |
| Camera and mount | 640x480 image frames up to 62.50 fps | Raspberry Pi power, rigid mounting, lighting | Determines what the vision pipeline can observe |
| Vision process | Wall and obstacle measurements | Camera frames, HSV thresholds, ROI configuration | Sends fresh perception data to the main process |
| State machine | Challenge state and maneuver selection | Vision measurements, lap and turn tracking | Converts detected track conditions into behavior |
| PD controller | Steering correction and speed command | Wall or pillar target, tuned gains | Calculates the response needed to stay on the desired path |
| Serial interface | Asynchronous drive-command transport | USB connection, Arduino protocol | Transfers the newest command to the hardware controller |
| Arduino and actuators | PWM for ESC and servo | Serial commands, battery or USB power | Applies the requested speed and steering angle |
| Recorder and logs | Video, telemetry, and replay data | Shared frames, main-process log records | Provides evidence for tuning and risk reduction |

## Mechanical and Control Interaction

The mechanical design determines how the control system's commands affect the robot. The front servo uses a steering range of 30-150 degrees, with 90 degrees representing straight ahead. The rear-wheel-drive system was selected because it is lighter and simpler than front-wheel or four-wheel drive, but it also makes traction and steering stability important parts of controller tuning.

The controller therefore cannot be tuned independently of the drivetrain:

1. A larger steering correction changes the robot's turning radius and may make the robot oscillate between the walls.
2. A higher drive speed reduces the time available for the camera and controller to correct an error.
3. A camera mounted high on the mast improves the view of the track but also changes the perspective and the relationship between pixel measurements and physical distance.
4. Motor torque and available battery current limit how quickly the robot can accelerate after a turn.

For this reason, speed, PD gains, steering limits, and camera geometry are tuned together. A software improvement is only useful if the drivetrain can produce the requested response reliably.

## Power and Electrical Interaction

The Gens Ace 1300mAh 2S LiPo provides the main 7.4V supply. The drive motor and ESC use the battery rail directly, the ESC BEC powers the steering servo, and a buck regulator supplies 5V to the Raspberry Pi. The camera receives power through the Raspberry Pi, while the Arduino communicates with the Pi over USB.

The power architecture affects every other subsystem:

- Drive motor acceleration and servo movement create current spikes that can reduce the voltage available to the Raspberry Pi.
- A Raspberry Pi brownout can stop the vision and control processes even if the mechanical system is still powered.
- Motor and servo switching can introduce electrical noise into communication or sensor signals.
- The regulator and wiring must support the computational load of vision processing as well as the instantaneous actuator load.

The system is therefore organized so that high-current actuator loads and regulated compute power have clear supply paths. Connectors and cable routing also matter because a loose power connection can appear as a software or communication failure.

## Perception and Behavior Interaction

The camera is the primary sensor for both challenges. Frames are captured by the camera process and written into shared memory. A pipe signals the vision process when a new frame is available, so the image does not need to be copied between processes.

The vision process selects the challenge-specific interpretation:

- In the **open challenge**, black-pixel counts in left, right, and center regions estimate wall position and detect a wall ahead. The difference between the left and right measurements becomes the wall-following error.
- In the **obstacle challenge**, HSV masks and contours detect red and green pillars in addition to the walls. The controller targets the gap between a pillar and the nearby wall. Green pillars are passed on the left and red pillars are passed on the right.

The state machine adds temporal context to these measurements. For example, a corner is confirmed over several consecutive frames before a turn is started. This prevents one noisy frame from changing the robot's maneuver. During an obstacle response, the pillar target receives 85% of the control weight and the wall target receives 15%, allowing the robot to prioritize the gap while retaining general wall awareness.

## Software and Communication Interaction

The software is divided into parallel processes so that image capture, perception, recording, and control can progress independently. The main process waits for fresh vision results, runs the state machine and PD controller, and submits the resulting command to the `DriveCommandExecutor`.

The executor is an important interface between software timing and hardware timing:

1. The control loop can submit a command every frame without waiting for serial I/O.
2. The executor stores only the latest command.
3. A background worker sends the command when the serial link is available.
4. If a newer command arrives first, the older command is discarded.

This latest-wins behavior prevents serial latency from creating a backlog of obsolete steering commands. The Arduino client uses transaction IDs to match responses and respects `WAITMS` responses from the Arduino, which provides back-pressure when the hardware needs time before accepting another command.

## Data Freshness and Failure Behavior

The system is designed around fresh data rather than processing every item in sequence. Old camera frames, old vision results, and old drive commands are allowed to be dropped because they describe a past robot position.

This design gives each interface a clear failure behavior:

- If vision takes too long, the main process should use the newest available result rather than a growing queue of old results.
- If serial transmission is slow, the executor replaces the pending command rather than delaying newer corrections.
- If a pillar is not detected reliably, the obstacle behavior can fall back toward wall following instead of treating a single uncertain detection as a confirmed maneuver.
- If the recorder is enabled, it observes the system for replay and diagnosis but does not need to block the control loop.

The most important limitation is that the camera is the only sensor currently used by the challenge runners. Lighting changes, occlusion, and camera vibration can therefore affect both perception and control. This is an intentional trade-off: the single-camera approach reduces weight, cost, synchronization work, and additional failure modes, while HSV calibration and repeated track testing address its limitations.

## Interaction-Driven Design Decisions

The following decisions were made because of subsystem interactions rather than because one component was optimal in isolation:

1. **Rear-wheel drive** was chosen because the simpler drivetrain reduces mechanical complexity and leaves more room for reliable software and testing.
2. **A tall camera mount** was chosen because the view of the track is more useful to vision than a low mount, even though the geometry must be accounted for during tuning.
3. **A single OV5647 camera** was chosen because it provides the required color information without the data-fusion and synchronization cost of extra sensors.
4. **Parallel processes and shared memory** were chosen because blocking camera capture or image copies would reduce the control loop's responsiveness.
5. **Latest-wins command scheduling** was chosen because a fresh steering correction is more valuable than guaranteed delivery of an outdated command.
6. **A conservative obstacle target blend** was chosen because obstacle avoidance must work with the wall-following behavior rather than completely replacing it.

## Summary

The robot's performance is determined by the interactions between its subsystems. Mechanical geometry limits the response that the controller can request, the power system determines whether compute and actuation remain stable, and the camera placement determines the quality of the measurements used by vision. The software architecture connects these constraints through fresh-data pipelines, challenge-specific state machines, and asynchronous serial commands.

The system is successful when the complete feedback loop remains stable: the camera observes the track, vision provides useful measurements, the controller makes a timely decision, the Arduino applies it, and the drivetrain produces predictable motion for the next observation. This is why changes are tested at the system level rather than judged only by the performance of an individual subsystem.

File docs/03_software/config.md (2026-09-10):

# Config Details

[Back to Software Overview](../../README.md)

---

## Overview

All settings live in the global [`Config`](https://apostla-api-reference.web.app/lib.html#piclient.core.lib.Config) object returned by [`GLOBAL_CONFIG()`](https://apostla-api-reference.web.app/lib.html#piclient.core.lib.GLOBAL_CONFIG). Nothing is hardcoded — if you want to change a speed, a gain, or a color threshold, you change the config file, not the code. Once the robot starts, the config is locked and cannot be changed mid-run.

---

## The Config File

Edit `piclient.toml` in the root of the repo:

```toml
[CameraConfig]
OUTPUT_WIDTH = 512
OUTPUT_HEIGHT = 384

[OpenChallengeConfig]
WALL_FOLLOW_KPKD = [0.5, 0.0]
CORNER_TURN_KPKD = [1.0, 0.0]
MAX_SPEED = 0.4

[ClientConfig]
SERIAL_PORT = "/dev/ttyACM0"
```

---

## Override Priority

Settings can be changed in four ways. Higher in the list always wins:

| Priority | Method | Example |
| --- | --- | --- |
| 1 (highest) | CLI flag | `wro --CameraConfig.OUTPUT_WIDTH 640` |
| 2 | Environment variable | `WRO__CAMERACONFIG__OUTPUT_WIDTH=640` |
| 3 | piclient.toml | `OUTPUT_WIDTH = 640` |
| 4 (lowest) | Code defaults | Dataclass field values in config.py |

---

## What Can Be Configured

| Section | What it controls |
| --- | --- |
| [`CameraConfig`](https://apostla-api-reference.web.app/lib.html#piclient.core.lib.Config.CameraConfig) | Resolution, format, frame rate |
| [`ClientConfig`](https://apostla-api-reference.web.app/lib.html#piclient.core.lib.Config.ClientConfig) | Serial port for Arduino, baud rate |
| [`VisionConfig`](https://apostla-api-reference.web.app/lib.html#piclient.core.lib.Config.VisionConfig) | HSV thresholds, ROI sizes, perspective transform |
| [`OpenChallengeConfig`](https://apostla-api-reference.web.app/lib.html#piclient.core.lib.Config.OpenChallengeConfig) | PD gains, speed, turn detection thresholds, lap length |
| [`ObstacleChallengeConfig`](https://apostla-api-reference.web.app/lib.html#piclient.core.lib.Config.ObstacleChallengeConfig) | PD gains for obstacle avoidance, pillar detection settings |
| [`LiDARConfig`](https://apostla-api-reference.web.app/lib.html#piclient.core.lib.Config.LiDARConfig) | Serial port for LiDAR |
| [`GeneralConfig`](https://apostla-api-reference.web.app/lib.html#piclient.core.lib.Config.GeneralConfig) | Which challenge to run (`open` or `obstacle`), logging level |

---

[Lib - Apostla 0.0.1 documentation](https://apostla-api-reference.web.app/lib.html)

---

## Freeze

Once the robot starts, the config is frozen with [`Freezeable.freeze()`](https://apostla-api-reference.web.app/lib.html#piclient.core.lib.Freezeable.freeze). Any attempt to change a value mid-run throws an error. This prevents accidental changes during a competition run.

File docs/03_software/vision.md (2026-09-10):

# Vision Details

[Back to Software Overview](../../README.md)

---

## Overview

The [`VisionProcessor`](https://apostla-api-reference.web.app/vision.html#piclient.core.vision.VisionProcessor) pipeline reads camera frames and works out where the walls and obstacles are. It runs inside the vision process so it does not slow down the main control loop.

All frames are converted from BGR to HSV before any detection is done. HSV separates color from brightness, which makes detection more reliable under different lighting conditions.

---

## Open Challenge

For the open challenge there are no obstacles — just walls. [`OpenChallengeVisionProcessor`](https://apostla-api-reference.web.app/vision.html#piclient.core.vision.OpenChallengeVisionProcessor) produces the normalized wall measurements used by the controller.

The vision code looks at three regions of the frame:

- **Left ROI** — counts black pixels on the left side
- **Right ROI** — counts black pixels on the right side
- **Center ROI** — counts black pixels straight ahead

More black pixels in a region means the wall is closer. The difference between left and right is fed into the PD controller to keep the robot centered between the walls.

**Corner detection:** When the center ROI fills up with black pixels, a wall is straight ahead. This triggers a corner turn after being confirmed over several consecutive frames.

---

## Obstacle Challenge

The obstacle challenge adds red and green pillars to the track. [`ObstacleChallengeVisionProcessor`](https://apostla-api-reference.web.app/vision.html#piclient.core.vision.ObstacleChallengeVisionProcessor) detects the walls and pillars and returns [`WallsAndObstacles`](https://apostla-api-reference.web.app/vision.html#piclient.core.vision.WallsAndObstacles) data containing [`VisionObject`](https://apostla-api-reference.web.app/vision.html#piclient.core.vision.VisionObject) instances.

**Wall detection:** Walls are found as contours rather than pixel counts. The distance is measured as the gap between the wall's center of mass (moments) and the frame center.

**Pillar detection:**

- The frame is masked for red and green HSV ranges separately
- The largest contour in each mask is taken as the detected pillar
- Red requires two HSV masks because red wraps around the hue wheel (0° and 180°)

**Steering target:** A dynamic offset based on proximity to the pillar is used as the steering target. The robot steers toward the gap between the wall and pillar, with a larger offset when the pillar is closer. The control output from this target is integrated with 85% weight on the pillar target and 15% weight on the wall target. This allows the robot to steer toward the gap while still keeping a general awareness of the wall's position.
**WRO rule:** Green pillars must be passed on the left. Red pillars must be passed on the right.

---

## HSV Color Ranges

All thresholds are set in `piclient.toml` under `[VisionConfig]`. Tune these under competition lighting before a run using the tools in `utils/`.

| Color | Notes |
| ----- | --- |
| Black (walls) | Low value, low saturation |
| Red (pillars) | Two ranges needed due to hue wrap-around |
| Green (pillars) | Single range around hue 40–80 |

---

## Tuning Tools

The `utils/` folder has interactive tools for tuning vision settings:

```bash
python PiClient/utils/color_threshold_tuner.py
```

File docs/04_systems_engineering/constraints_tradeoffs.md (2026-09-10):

# Constraints and Trade-offs

When engineering a robust and reliable system, there are always constraints and trade-offs to consider. These can include cost, weight, complexity, performance, and reliability. In this document, we will discuss the key constraints and trade-offs that influenced our design decisions for the 2026 WRO Future Engineer category.

## Constraints

Constraints are limitations or requirements that must be satisfied in order for the system to function as intended. These constraints can be imposed by competition rules, physical limitations, or performance requirements.

We can organize our constraints into a hierarchy, beginning with the most fundamental ("Obvious") constraints at the highest level, and moving down to more specific ("Derived") constraints at the lower levels.
To help us process and design around the constraints, we can use a "Constraint Tree" to visualize the relationships between the constraints and how they influence our design decisions.

### Constraint Tree

1. **Compliance with WRO rules and regulations**.
    1. The robot must remain within the competition size, mass, power, and mechanical limits.
        1. The chassis, drivetrain, and sensor mounts must fit within the permitted envelope.
        2. The battery and power system must remain within allowed limits.
        3. The robot must remain stable and not pose a hazard to itself or other teams.
    2. The robot must be our own work and not violate any intellectual property rights.
        1. All components must be designed and built by our team, or be commercially available and legally usable.
        2. The robot must not use any software or algorithms that are not our own work, unless they are under an OSI-approved license.
        3. The robot must avoid any design or implementation that would be considered cheating or unfair to other teams.
    3. The robot must follow timing, startup, reset, and stop procedures required by the competition.
        1. Start-up must be repeatable and not rely on undocumented manual steps.
        2. The robot must safely stop when a run ends or a fault is detected.
        3. Competition resets must restore the robot to a known-good state.

2. **Maximize score within the competition rules**.
    1. Complete the challenge objectives as reliably as possible.
        1. The robot must stay on task during wall following and path progression.
        2. The robot must identify and avoid obstacles without losing time or control.
        3. The robot must complete each lap and finish in the expected stop zone.
    2. Minimize time lost to recovery, hesitation, and detours.
        1. The control loop must respond quickly to the latest sensor data.
        2. The robot must avoid oscillations or unnecessary steering corrections.
        3. The robot must reduce the penalty cost of false detections or noisy sensor readings.
    3. Optimize the value of each decision to improve the score per unit time.
        1. High-value actions should have priority over low-value maneuvers.
        2. The system should favor stable task completion over risky aggressive moves.
        3. The robot must be able to exploit the scoring structure without violating rule constraints.

3. **Keep the design simple, reliable, and robust**.
    1. Reduce unnecessary complexity in hardware and software.
        1. Each subsystem should have a clear, single purpose.
        2. Interfaces between modules should be clean and well-defined.
        3. The system should avoid over-engineered features that do not increase score.
    2. Reduce failure modes and recovery burden.
        1. The drivetrain, sensor package, and control software should be tolerant of small calibration shifts.
        2. The robot should degrade gracefully if a sensor temporarily misreads a target.
        3. The system must be easy to debug during a competition setup or test session.
    3. Make the platform maintainable after repeated testing.
        1. Electrical connections should be accessible and labeled.
        2. Camera, serial, and control logic should be modular, so configuration changes stay localized.
        3. Adjustments to thresholds, gains, and tuning values should be easy to validate.

4. **Maximize speed while preserving reliable course completion**.
    1. Increase throughput of sensing and decision-making.
        1. The camera pipeline should keep up with the required frame rate.
        2. The vision and control logic should process new data without blocking each other.
        3. The robot should avoid stale-frame behavior by always acting on the latest information.
    2. Improve the responsiveness of the drive system.
        1. Steering and propulsion must change quickly enough to maintain course accuracy.
        2. The serial command system must not become a bottleneck during fast runs.
        3. The drive loop should minimize latency while remaining stable under load.
    3. Match speed to available energy and mechanical capability.
        1. The drivetrain must provide enough torque and traction for the chosen acceleration profile.
        2. Motor and battery selection should support the speed goals without overheating or sagging.
        3. The robot must still recover from minor disturbances without hitting obstacles or crashing into a wall.

### Higher-Order Constraint Summary

At the system level, the top-level constraints are not independent. The design must first satisfy the rule envelope (`1.x`), then the performance envelope (`2.x`), then the reliability envelope (`3.x`), and finally the speed envelope (`4.x`). In practice, all four are evaluated together, but the order matters because a design that violates rule constraints or fails reliability cannot be considered a viable solution even if it scores well or runs quickly.

## Trade-offs

Oftentimes, when engineering a system, we must make trade-offs between competing constraints. For example, increasing speed may reduce reliability, or adding more sensors may increase complexity and weight. Before we discuss the specific trade-offs we made in our design, it is important to understand the general principles of trade-offs in engineering.

### Trade-off Principles

In our engineering methodology, hard constraints (1.x–3.x) represent non-negotiable operational boundaries, while trade-offs represent bounded optimizations (e.g., speed vs. controller stability). Our goal is to maximize performance within the parameter space defined by our hard constraints. (It's important to define constraints first, because they define the solution space. Trade-offs don't matter when the judge sees your robot and says "That's illegal"!)

A trade-off is a decision to sacrifice one aspect of the system in order to improve another. For example, we may choose to reduce the weight of the robot in order to increase its speed, or we may choose to add more sensors in order to improve its reliability. Trade-offs are often necessary because no single design can optimize all aspects of a system simultaneously.

#### How we make trade-offs

We ask a series of questions to evaluate the trade-offs:

1. **Does the trade-off satisfy the solution space defined by the constraints?** If not, the trade-off is invalid and must be rejected.
2. **What aspects of the system are improved by the trade-off?** We evaluate the benefits of the trade-off, weighing more heavily on critical aspects of the system `(1.x–2.x)` than on less critical aspects `(3.x-4.x)`.
3. **What aspects of the system are sacrificed by the trade-off?** We evaluate the costs of the trade-off, weighing more heavily on critical aspects of the system `(1.x–2.x)` than on less critical aspects `(3.x-4.x)`.
4. **What is the opportunity cost of the trade-off?** We evaluate what other trade-offs could have been made instead, and whether the opportunity cost of implementing this trade-off is worthwhile in light of other potential trade-offs.
5. **Is the trade-off reversible?** We evaluate whether the trade-off can be reversed or modified later if it proves to be a poor decision. If the trade-off is irreversible, we must be more cautious in our evaluation.
  Software trade-offs are often reversible, which provides much more room for experimentation and tuning. Hardware trade-offs are often irreversible, which requires more careful consideration before making a decision.

After evaluating all these factors, we don't implement a hyper-optimized solution right away. Instead, we implement a "quick and dirty" solution that meets the basic requirements, but allows us to test the system and gather data, giving us space to re-evaluate the trade-off we made before committing to a final design. This iterative approach allows us to make informed decisions and avoid costly mistakes.

### Key Trade-offs in Our Design

Because early choices dictate downstream options (particularly across iterative cycles), we model our major design decisions as a Directed Acyclic Graph (DAG). Primary hardware choices (like steering geometry) form the root nodes, branching down into dependent software and tuning trade-offs.

[ insert a cool flowchart here ]

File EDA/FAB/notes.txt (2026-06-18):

Notes:
1. I may have made a couple mistakes/picked impossible footprints because this is my first design +
I am a 9th grader.
2. All components (except capacitors) should be rated >12V
3. All capacitors should be rated >16V
4. I can fix any minnor issues like picking an impossibly small footprint/random unconnected track/ugly silkscreen

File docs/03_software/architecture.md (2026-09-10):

# Architecture Details

[Back to Software Overview](../../README.md)

## The Four Processes

The robot runs four separate OS processes in parallel so that the camera, vision, and main control loop are pipelines rather than sequential. This raises effective throughput to the maximum of the four, rather than the sum of the four.

### [`Camera`](https://apostla-api-reference.web.app/interface.html#piclient.core.interface.AsyncCamera) Process

- Captures frames from the Pi camera through [`AsyncCamera`](https://apostla-api-reference.web.app/interface.html#piclient.core.interface.AsyncCamera)
- Writes each frame directly into shared memory, so no copying is needed
- Sends a signal through a pipe to tell the vision process a new frame is ready

### [`Vision`](https://apostla-api-reference.web.app/vision.html#piclient.core.vision.VisionProcessor) Process

- Reads the frame from shared memory when it gets the signal
- Runs [`VisionProcessor`](https://apostla-api-reference.web.app/vision.html#piclient.core.vision.VisionProcessor) and the challenge-specific [`OpenChallengeVisionProcessor`](https://apostla-api-reference.web.app/vision.html#piclient.core.vision.OpenChallengeVisionProcessor) or [`ObstacleChallengeVisionProcessor`](https://apostla-api-reference.web.app/vision.html#piclient.core.vision.ObstacleChallengeVisionProcessor) to find walls and obstacles
- Sends the results through a pipe to the main process
- Multiple vision threads run at once inside this process to keep up with the camera

### [`Recorder`](https://apostla-api-reference.web.app/interface.html#piclient.core.interface.Recorder) Process

- Reads frames from shared memory and saves them to a video file
- Receives log records from the main process and saves them via timed pickle dumps
- A replay generator can combine the video and log records into an annotated replay video for post-run analysis
- The [`Recorder`](https://apostla-api-reference.web.app/interface.html#piclient.core.interface.Recorder) process is optional and can be disabled to save CPU cycles if logging is not needed

### Main Process

- Waits for fresh vision results from the vision process
- Runs the [`StateMachine`](https://apostla-api-reference.web.app/lib.html#piclient.core.lib.StateMachine) and [`PD`](https://apostla-api-reference.web.app/lib.html#piclient.core.lib.PD) controller
- Submits drive commands to [`DriveCommandExecutor`](https://apostla-api-reference.web.app/interface.html#piclient.core.interface.DriveCommandExecutor)
- Also handles the debug video overlay

## Data Flow

<p align="center">
  Architecture diagram showing the four processes and their data flow
</p>
<p align="center"><i>Data flow diagram for the four processes.</i></p>

## Latest-Wins Design

The system always acts on the freshest data:

- If a new camera frame arrives before the old one is processed, the old one is dropped
- If a new drive command is submitted before the old one is sent to the Arduino, the old one is overwritten
- The vision pipe holds only the 3 most recent results and yields them newest-first

This means the robot never acts on stale data and never builds up a backlog.

## API and implementation map

The [Apostla API Reference](https://apostla-api-reference.web.app/) documents the public package. Use the source links below when the design discussion needs implementation detail.

| Area | Public API | Implementation |
| ---- | --- | --- |
| Camera | [`AsyncCamera`](https://apostla-api-reference.web.app/interface.html#piclient.core.interface.AsyncCamera), [`get_frame_async()`](https://apostla-api-reference.web.app/interface.html#piclient.core.interface.AsyncCamera.get_frame_async), [`stream()`](https://apostla-api-reference.web.app/interface.html#piclient.core.interface.AsyncCamera.stream) | [`async_camera.py`](https://apostla-api-reference.web.app/_modules/piclient/core/interface/async_camera.html) |
| Serial drive | [`Client`](https://apostla-api-reference.web.app/interface.html#piclient.core.interface.Client), [`drive_motors()`](https://apostla-api-reference.web.app/interface.html#piclient.core.interface.Client.drive_motors), [`set_servo_angle()`](https://apostla-api-reference.web.app/interface.html#piclient.core.interface.Client.set_servo_angle), [`set_motor_speed()`](https://apostla-api-reference.web.app/interface.html#piclient.core.interface.Client.set_motor_speed) | [`client.py`](https://apostla-api-reference.web.app/_modules/piclient/core/interface/drive/client.html) |
| Command scheduling | [`DriveCommandExecutor`](https://apostla-api-reference.web.app/interface.html#piclient.core.interface.DriveCommandExecutor), [`submit()`](https://apostla-api-reference.web.app/interface.html#piclient.core.interface.DriveCommandExecutor.submit) | [`comm_protocol.py`](https://apostla-api-reference.web.app/_modules/piclient/core/interface/comm_protocol.html) |
| Vision | [`VisionProcessor`](https://apostla-api-reference.web.app/vision.html#piclient.core.vision.VisionProcessor), [`VisionObject`](https://apostla-api-reference.web.app/vision.html#piclient.core.vision.VisionObject), [`OpenChallengeWalls`](https://apostla-api-reference.web.app/vision.html#piclient.core.vision.OpenChallengeWalls), [`WallsAndObstacles`](https://apostla-api-reference.web.app/vision.html#piclient.core.vision.WallsAndObstacles) | [`base.py`](https://apostla-api-reference.web.app/_modules/piclient/core/vision/base.html), [`data.py`](https://apostla-api-reference.web.app/_modules/piclient/core/vision/data.html), [`open_challenge.py`](https://apostla-api-reference.web.app/_modules/piclient/core/vision/open_challenge.html) |
| Control | [`PD`](https://apostla-api-reference.web.app/lib.html#piclient.core.lib.PD), [`PD.tick()`](https://apostla-api-reference.web.app/lib.html#piclient.core.lib.PD.tick), [`StateMachine`](https://apostla-api-reference.web.app/lib.html#piclient.core.lib.StateMachine), [`TransitionManager`](https://apostla-api-reference.web.app/lib.html#piclient.core.lib.TransitionManager) | [`controller.py`](https://apostla-api-reference.web.app/_modules/piclient/core/lib/controller.html) |
| Configuration | [`Config`](https://apostla-api-reference.web.app/lib.html#piclient.core.lib.Config), [`GLOBAL_CONFIG()`](https://apostla-api-reference.web.app/lib.html#piclient.core.lib.GLOBAL_CONFIG), [`Freezeable.freeze()`](https://apostla-api-reference.web.app/lib.html#piclient.core.lib.Freezeable.freeze) | [`config.py`](https://apostla-api-reference.web.app/_modules/piclient/core/lib/config.html) |
| Challenge entry points | [`run_open_challenge()`](https://apostla-api-reference.web.app/open_challenge.html#piclient.open_challenge.run_open_challenge), [`run_obstacle_challenge()`](https://apostla-api-reference.web.app/obstacle_challenge.html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) | [`runner.py`](https://apostla-api-reference.web.app/_modules/piclient/open_challenge/runner.html), [`runner.py`](https://apostla-api-reference.web.app/_modules/piclient/obstacle_challenge/runner.html) |

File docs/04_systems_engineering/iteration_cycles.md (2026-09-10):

# Design Iteration

When designing a complex system, we often face trade-offs between different design choices. These trade-offs can be difficult to evaluate, as they often involve multiple factors and dependencies. To help us make informed decisions, we use an iterative design process that allows us to test and refine our designs over time.

## Practical Examples

 For detailed mechanical iterations, see [Mechanical Iterations](../01_mechanical/mechanical_iterations.md).

 For power iterations, see [Power Iterations](../02_power_sensors/power_architecture.md#iterations)

### Python Packaging

Our Python packaging design also went through several iterations, each with its own set of trade-offs and limitations. The table below summarizes the different approaches we considered for packaging our Python code, along with their design goals, limitations, and takeaways.

| Version | Design Goals | Limitations | Takeaways |
| --- | --- | --- | --- |
| 1 | No packaging, just a single src directory with module-level imports. | Isolation of concerns and DRY suffered, and the architecture becomes tightly coupled without clear interfaces and boundaries. | A single src directory is not a sustainable architecture considering the scope of our project. |
| 2 | Independently maintain a simpler `src_min` implementation with a single src directory, forgoing complex multiprocessing and asynchronous IO. | While the simple implementation is easier to maintain, it doesn't meet our performance constraints, and the additional burden of maintaining two separate implementations is significant. | A simpler, slower implementation is a trade-off we couldn't accept given our latency and throughput requirements. |
| 3 | Use multiple sub-packages within a single src directory. | The architecture is still tightly coupled, and the sub-packages are not easily reusable or distributable. | Sub-packages are a step in the right direction, but they do not provide enough isolation of concerns or reusability. |
| 4 | Adopt a namespace package architecture with multiple sub-packages, each with distribution metadata (`pyproject.toml`) and clearly defined exports. | Complex packaging requirements, requiring deep understanding of Python packaging and distribution. | Namespace packages provide a sustainable architecture with clear interfaces and independently distributable components. |

We've adopted the gold standard for Python packaging: a namespace package architecture that provides clear interfaces and independently distributable components. While this approach introduces complex packaging constraints, it is a sustainable architecture that can support the growth and evolution of our project over time. It's a solution many Python projects have adopted, and it is the recommended approach for large, complex projects that require modularity and reusability.

Our codebase is highly complex, with a multi-process producer-consumer model, asynchronous IO, and low-latency/high-throughput requirements. Our pipeline would have experienced untraceable race conditions and shared memory allocation failures if the interfaces between producers and consumers (Camera (Asynchronous) → SHM (Shared Memory) → Vision Processor (multithreaded) → State Machine/Controller → Asynchronous Hardware Interfaces and Custom Protocols → Hardware) were not clearly defined and enforced. The level of introspection and logging currently in place would not have been possible without the namespace package architecture, as the recorder and logging consumers would not have been able to interface with the tightly coupled camera → processor → control pipeline.

Even though we had to invest significant time and effort into understanding and implementing a namespace package architecture, it has paid off in the long run. We're able to distribute our codebase to potential future teams, and they can easily understand and modify the code without having to navigate a tightly coupled monolithic architecture. We invite you to install our packages and play around on your own robots! Please see our [Setup Guide](./setup_guide.md) for instructions on how to install and use our packages.

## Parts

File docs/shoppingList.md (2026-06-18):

# Shopping List

> [5V, 5A Step-Down Voltage Regulator D24V50F5](https://www.pololu.com/product/2851)  
> [7.4V Li-ion Battery 3000mAh 2S with Deans T Plug](https://www.amazon.ca/PCEONAMP-7-4V-3000mAh-Deans-Plug/dp/B0CHMH4VDT)  
> [ProTek RC 500BL](https://www.amainhobbies.com/protek-rc-500bl-black-label-1-12-high-torque-brushless-mini-servo-ptk-500bl/p1299941)  
> Make Custom PCB and generate BOM (ongoing)

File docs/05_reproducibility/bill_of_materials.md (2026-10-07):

# Bill of Materials

[Back to README](../../README.md)

This document lists all components used to build the robot, including electronics, mechanical parts, and consumables.

---

## Electronics

| Component | Model | Purpose | Quantity | Price (CAD) |
| --- | --- | --- | --- | --- |
| Main Compute | [Raspberry Pi 5 (8GB)](https://www.amazon.ca/RasTech-Raspberry-Pi-refroidisseur-inclus/dp/B0DQX6JPVM) | Vision, control logic, Arduino communication | 1 | $170 |
| Microcontroller | [Arduino Nano](https://store-usa.arduino.cc/products/arduino-nano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) | PWM output to ESC and servo | 1 | $26 |
| Drive Motor | [Furitek Micro Komodo 1212 3450KV](https://furitek.com/products/furitek-micro-komodo-1212-3456kv-brushless-motor-with-15t-steel-pinion-for-fury-wagon-fx118) | Rear wheel drive | 1 | $35 |
| ESC | [Furitek Lizard Pro 30A/50A](https://furitek.com/products/combo-of-furitek-lizard-pro-30a-50a-brushed-brushless-esc-for-axial-scx24-with-bluetooth) | Motor speed control | 1 | $80 |
| Servo Motor | [Hitec HS-5055MG](https://hitecrcd.com/hs-5055mg-economy-metal-gear-feather-servo/) | Steering control | 1 | $25 |
| Camera | [OV5647 5MP 1080P](https://www.amazon.ca/dp/B0D324RKRZ) | Wall, pillar, and corner line detection | 1 | $35 |
| Battery | [Gens Ace 1300mAh 2S LiPo 45C](https://genstattu.com/gens-ace-1300mah-2s-7-4v-45c-g-tech-lipo-battery-pack-with-deans-plug/) | Main power source | 1 | $21 |
| Voltage Regulator | [Yahboom Regulator](https://category.yahboom.net/products/asrm?srsltid=AfmBOoq43PT68v2hMJWeWC1laU7sbZsMzVec32_oD88Ob5BD8jPdT2T3) | Lowers 7.4V from battery to Pi | 1 | $15 |
| Power Switch | — | Main battery on/off | 1 | — |
| Deans-T Connector | — | Battery main connector | 2 | — |

---

## Mechanical

| Component | Purpose | Quantity | Price (CAD) |
| --- | --- | --- | --- |
| Wheels (35mm rubber, 1/28 scale) | [1/28 RC Drift Tires](https://www.amazon.ca/AllinRC-Pre-glued-Compatible-WLtoys-Racing/dp/B0B4DH61L9) | Rear and front wheels (4) | $27 (pack) |
| RC Differential Gearbox (1/4 ratio) | Drive power to rear wheels | 1 | — |
| 6mm Ball Bearings | Axle support in rear body mount | 4 | — |
| M2 Screws | Securing small components | ~20 | — |
| M2.5 Screws | Raspberry Pi mounting (nylon) | ~8 | — |
| M3 Screws | Sensor tower, chassis mounts | ~16 | — |

---

## Tools Required

| Tool | Purpose |
| --- | --- |
| FDM 3D Printer | Printing chassis and mount parts |
| Soldering Iron | Wiring and connector work |
| Solder | — |
| Electrical Tape | Wire insulation and securing |
| Heat Shrink | Connector protection |
| Wire Strippers | Wiring |
| Multimeter | Voltage and continuity checks |
| Drill | Chassis modifications |
| M2 / M2.5 / M3 Hex Driver | Fastening screws |

---

## Total Estimated Cost

| Category | Estimated Cost (CAD) |
| --- | --- |
| Electronics | ~$442 |
| Mechanical | ~$27 |
| Filament | ~$10 |
| **Total** | **~$469** |

*Prices are approximate and based on retail cost at time of purchase. Some components were sourced from existing supplies.*

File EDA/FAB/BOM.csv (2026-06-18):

Reference | Qty | Datasheet | Value (Manufacturer Part No.) | Footprint
C_BOOST1 | 1 | ~ | GRM155R71C103KA01D | Capacitor_SMD:C_0402_1005Metric
CP_HL1 | 1 | ~ | GCM155R71C473KA37D | Capacitor_SMD:C_0402_1005Metric
PI_BYP1 | 1 | ~ | EMK105ABJ474KV-F | Capacitor_SMD:C_0402_1005Metric
AVDD_BYP1 | 1 | ~ | GRM033R61C105ME15D | Capacitor_SMD:C_0402_1005Metric
BK_BYP1 | 1 | ~ | GRM033R61C105ME15D | Capacitor_SMD:C_0201_0603Metric
BYP_SRV1 | 1 | ~ | GRM033R61C105ME15D | Capacitor_SMD:C_0402_1005Metric
BYP_VM1 | 1 | ~ | GRM033R61C105ME15D | Capacitor_SMD:C_0402_1005Metric
C_PUMP1 | 1 | ~ | GRM033R61C105ME15D | Capacitor_SMD:C_0402_1005Metric
DVDD_BYP1 | 1 | ~ | GRM033R61C105ME15D | Capacitor_SMD:C_0402_1005Metric
SRVOUT_BYP1 | 1 | ~ | GRM033R61C105ME15D | Capacitor_SMD:C_0201_0603Metric
PI_BULK1 | 1 | https://www.we-online.com/catalog/datasheet/860160572002.pdf | 860160572002 | 860160572002:CAP_5X11_WRE
PI_BULK2 | 1 | https://www.we-online.com/catalog/datasheet/860160572002.pdf | 860160572002 | 860160572002:CAP_5X11_WRE
PI_BULK3 | 1 | https://www.we-online.com/catalog/datasheet/860160572002.pdf | 860160572002 | 860160572002:CAP_5X11_WRE
SRV_BK1 | 1 |  | SPM10065VT-680M-D | SPM10065VT-680M-D:IND_SPM10065VT-680M-D
BK_BULK1 | 1 | https://www.we-online.com/catalog/datasheet/860040573004.pdf | 860040573004 | 860040573004:CAP_WCAP-ATUL_06.3X11.0_WRE
PI_OUT3 | 1 | https://www.we-online.com/catalog/datasheet/860040573004.pdf | 860040573004 | 860040573004:CAP_WCAP-ATUL_06.3X11.0_WRE
SRV_BULK1 | 1 | https://www.we-online.com/catalog/datasheet/860040573004.pdf | 860040573004 | 860040573004:CAP_WCAP-ATUL_06.3X11.0_WRE
BULK_VM2 | 1 | 16ZLH470MEFCT78X11.5 | 16ZLH470MEFCT78X11.5 | 16ZLH470MEFCT78X11.5:CAP_YX_8X11P5_RUB
PI_OUT2 | 1 | 16ZLH470MEFCT78X11.5 | 16ZLH470MEFCT78X11.5 | 16ZLH470MEFCT78X11.5:CAP_YX_8X11P5_RUB
SRVOUT_BULK1 | 1 | 16ZLH470MEFCT78X11.5 | 16ZLH470MEFCT78X11.5 | 16ZLH470MEFCT78X11.5:CAP_YX_8X11P5_RUB
PD_SRV1 | 1 | ~ | RC0402FR-075KL (Any 5.1k is acceptable) | Resistor_SMD:R_0402_1005Metric
FG_PU1 | 1 | ~ | RC0402FR-075KL (Any 5.1k is acceptable) | Resistor_SMD:R_0402_1005Metric
R1 | 1 | ~ | RC0402FR-075KL (Any 5.1k is acceptable) | Resistor_SMD:R_0402_1005Metric
R_BK1 | 1 | ~ | RC0402FR-075KL (Any 5.1k is acceptable) | Resistor_SMD:R_0402_1005Metric
SERVO_CATCH1 | 1 | 1N5825 | 1N5825 | 1N5825:1N5825_MCH
BLDC_3P1 | 1 | ~ | 4391 | Connector_JST:JST_PH_S3B-PH-K_1x03_P2.00mm_Horizontal
ARD_A1 | 1 | ~ | 61300811121 | Connector_PinHeader_2.54mm:PinHeader_1x08_P2.54mm_Vertical
ARD_C1 | 1 | ~ | 61300811121 | Connector_PinHeader_2.54mm:PinHeader_1x08_P2.54mm_Vertical
ARD_B1 | 1 | ~ | PH1-10-UA | Connector_PinHeader_2.54mm:PinHeader_1x10_P2.54mm_Vertical
D_FAULT1 | 1 | ~ | 150040RS73240 (Any LED is fine, prefer red) | LED_SMD:LED_0402_1005Metric
U2 | 1 | http://www.ti.com/lit/ds/symlink/lm2596.pdf | LM2596S-5.0 | Package_TO_SOT_SMD:TO-263-4
U3 | 1 | https://www.ti.com/lit/gpn/lm2678 | LM2678S-5.0 | LM2678S:TS7B
M1 | 1 | http://forums.parallax.com/uploads/attachments/46831/74481.png | M20-9990345 | Connector_PinHeader_2.54mm:PinHeader_1x03_P2.54mm_Horizontal
U1 | 1 | https://www.ti.com/lit/gpn/mcf8316a | MCF8316A1VRGFR | MCF8316A:RGF0040E-IPC_A
PI_CATCH1 | 1 | https://www.vishay.com/doc?94945 | VS-6TQ045S-M3 | VS-6TQ045S-M3:DPAK_045S-M3_VIS
J2 | 1 | ~ | (Not Applicable) | Connector_Wire:SolderWire-1.5sqmm_1x02_P7.8mm_D1.7mm_OD3.9mm
PI_OUT1 | 1 | ~ | ((Not Applicable) | Connector_Wire:SolderWire-1.5sqmm_1x02_P7.8mm_D1.7mm_OD3.9mm
L1 | 1 | SRP1038WA-220M | SRP1038WA-220M | SRP1038WA-220M:IND_SRP1038WA-220M_BRN

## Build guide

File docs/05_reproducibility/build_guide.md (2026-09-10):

# Build Guide

Start by viewing our [GitHub releases page](https://github.com/IaMaAVerYRANdOmPerSoN/WROFutureEngineer/releases/tag/v0.1.0) for the 3D printing files (.f3z, .step, .fxb)

Once printed, make sure you have all the materials in [Material List](./bill_of_materials.md)

We've provided a brief assembly video to help you get started. The video is a high-level overview of the assembly process and does not cover every detail. Please refer to the written instructions below for more detailed guidance.

Assembly Video (https://youtu.be/6nG1ul_CTjg)

## Turning System

The turning system is responsible for controlling the steering of the robot and allowing the front wheels to rotate smoothly.

### Assembly Steps

1. **Install the Steering Knuckles**
   - Place both steering knuckles inside their respective control arms.
   - Ensure that the knuckles are seated correctly and aligned with the mounting points on the control arms.
   - Check that both steering knuckles can move freely without excessive resistance.

2. **Install the Servo Horn**
   - Attach the servo horn securely onto the steering servo.
   - Ensure that the servo horn is positioned correctly so that it can provide the required range of motion for the steering system.

3. **Attach the Anti-Sway Arm**
   - Connect the anti-sway arm to the servo horn.
   - Make sure the connection is secure and that the arm is able to move through its full range without contacting surrounding components.

4. **Connect the Steering Components**
   - Attach the anti-sway arm to both steering knuckles.
   - Verify that both steering knuckles move together when the servo horn is rotated.
   - Check that there is no excessive play or looseness in the steering linkage.

5. **Install the Bearings and Wheels**
   - Insert the ball bearings into their designated mounting points.
   - Carefully install the wheels onto the steering knuckles.
   - Confirm that the wheels rotate smoothly and that the bearings are seated correctly.

6. **Mount the Turning System**
   - Position the completed turning system onto the Arduino Uno layout.
   - Align all mounting holes before inserting the screws.
   - Secure the assembly firmly while ensuring that the steering mechanism remains free to move.

<p align="center">
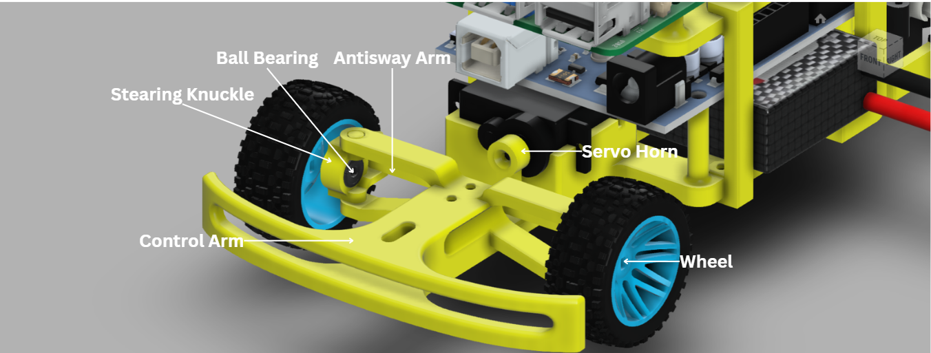
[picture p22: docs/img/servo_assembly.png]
  
</p>

---

## Differential System

The differential system transfers power from the motor to the wheels while allowing the wheels to rotate effectively during turns.

### Assembly Steps

1. **Mount the Furitek Motor**
   - Position the Furitek motor onto the rotating cage.
   - Align the motor with the designated mounting holes and secure it using the appropriate screws.
   - Ensure that the motor is firmly attached and does not shift during operation.

2. **Install the Rotating Cage**
   - Place the rotating cage into the designated differential layout.
   - Carefully align the cage with the mounting points and ensure that all components are properly seated.
   - Secure the rotating cage using the appropriate screws.

3. **Install the Differential**
   - Position the pre-assembled differential into the rotating cage.
   - Secure the differential firmly in place.
   - Rotate the differential by hand to verify that it moves smoothly without binding or unusual resistance.

4. **Install the Ball Bearings**
   - Insert the ball bearings into their designated positions within the differential assembly.
   - Ensure that each bearing is fully seated and aligned correctly.

5. **Install the Dog-Bone Axles**
   - Insert the dog-bone axles into the differential.
   - Check that the axles are properly engaged with the differential and can rotate freely.

6. **Attach the Wheels**
   - Install the wheels onto the dog-bone axles.
   - Secure each wheel firmly while ensuring that it can rotate without obstruction.
   - Rotate the wheels manually to confirm that the differential and axles operate smoothly.

<p align="center">
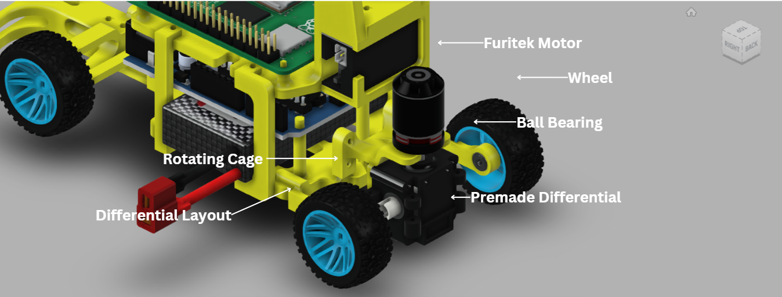
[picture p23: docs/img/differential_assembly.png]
  
</p>

---

# Main Chassis

The main chassis integrates the turning system, differential system, and electronic components into a single structure.

## Arduino Uno Layout

1. **Install the Drive and Steering Systems**
   - Position the completed differential system onto the Arduino Uno chassis layout.
   - Align the mounting holes and secure the differential system using the appropriate screws.
   - Position the turning system onto the front of the chassis and secure it in place.
   - Confirm that both systems are properly aligned before continuing.

2. **Mount the Arduino Uno**
   - Place the Arduino Uno onto its designated mounting position on the chassis.
   - Align the mounting holes and secure the board using the appropriate screws and hardware.
   - Ensure that the board is firmly mounted without placing unnecessary pressure on the PCB.

3. **Install the Chassis Connectors**
   - Attach the four connectors to their designated mounting locations.
   - Align each connector carefully with the chassis.
   - Secure all four connectors using the appropriate screws.
   - Verify that the connectors are firmly attached and do not interfere with any moving components.

4. **Final Mechanical Check**
   - Inspect the entire Arduino Uno layout for loose screws or incorrectly positioned components.
   - Rotate the wheels manually to ensure that the drivetrain operates smoothly.
   - Move the steering system through its full range of motion to confirm that there are no mechanical obstructions.

<p align="center">
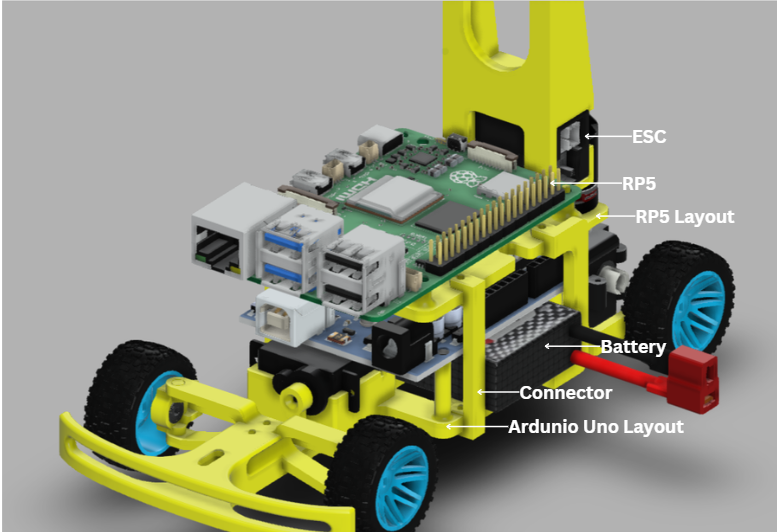
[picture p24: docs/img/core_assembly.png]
  
</p>

---

## RP5 Layout

The RP5 layout provides the mounting structure for the robot's computing hardware, camera system, and electronic speed controller.

### Assembly Steps

1. **Install the Chassis Connectors**
   - Position the four connectors onto their designated mounting points on the RP5 layout.
   - Align the connectors carefully with the chassis holes.
   - Secure each connector using the appropriate screws.

2. **Mount the RP5**
   - Carefully position the RP5 onto the designated mounting area.
   - Align the board with the four connectors.
   - Secure the RP5 firmly using the appropriate screws.
   - Ensure that the board is stable and that no cables or components are being compressed.

3. **Install the Camera Mast**
   - Position the camera mast onto its designated mounting location.
   - Align the mounting holes and secure the mast using the appropriate screws.
   - Confirm that the mast is straight and firmly attached to the chassis.

4. **Mount the Camera**
   - Attach the camera to the top of the camera mast.
   - Secure the camera so that it remains stable during robot movement.
   - Adjust the camera orientation to provide a clear forward-facing view.

5. **Install the ESC**
   - Slide the ESC into its designated position within the RP5 layout.
   - Ensure that the ESC is securely positioned and that its cables have sufficient clearance.
   - Route the cables neatly to prevent them from interfering with the wheels, drivetrain, or steering components.

6. **Final Assembly Inspection**
   - Check that all hardware is securely fastened.
   - Confirm that the camera mast and camera are stable.
   - Ensure that all electronic components are properly positioned and that no wires are obstructing moving mechanical components.
   - Manually test the wheels and steering one final time before powering on the robot.

<p align="center">
  
</p>

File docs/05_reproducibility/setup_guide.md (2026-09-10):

# Setup

> [!NOTE]
> This guide assumes you are using a Raspberry Pi with at least 4GB of RAM, running Raspberry Pi OS (64-bit) Bookworm or later. If you are using a different OS or hardware, these instructions may not work, and you may need to adapt them to your environment. We cannot provide support for non-Raspberry Pi OS systems.
>
> Python, `pip`, and picamera2 are bundled with Raspberry Pi OS (64-bit) Bookworm or later. If you are using a different OS, you will need to install these dependencies manually.
>
> If you want to build the software from source, see [Building from Source](./building_from_source.md). We recommend using the prebuilt wheel for most use cases.

## Hardware Setup

First, you should assemble the robot according to the instructions in [Build Guide](./build_guide.md). Please make sure to follow the assembly instructions carefully, as improper assembly can lead to hardware damage or malfunction. Please ensure all electrical connections are secure and insulated, and that the robot is powered off when making adjustments.

## Software Setup

After building the robot and imaging the Raspberry Pi, you can set up the software on the Pi. The easiest way is to use the prebuilt wheel. `pip` (or equivalent) will automatically install the wheel and its dependencies.

If you want to build from source, see [Building from Source](./building_from_source.md).

> [!WARNING]
> picamera2 is not a dependency of the wheel. We strongly recommend using the system-wide installation, which is included in the Raspberry Pi OS image.
> If you are using a virtual environment, use `--system-site-packages` option to access the system-installed picamera2.
>
> picamera2 is not supported on non-Raspberry Pi OS systems. Picamera2, and by extension our software, will not work without Raspberry Pi's libcamera binaries.
> Please do not attempt to install picamera2 from source or use a different camera library; We cannot provide support for these configurations.

Install the `piclient` package, and its optional dependencies with your preferred package manager. For example, using pip/venv: <!-- Replace with link once published to PyPI -->

```bash
python -m venv --system-site-packages .venv
source .venv/bin/activate
pip install piclient[all]
```

That's it! You can now run the open challenge with `wro` or the obstacle challenge with `wro --GeneralConfig.CHALLENGE obstacle`. For more information on configuration and tuning, see [Configuration and Tuning](../03_software/config.md).

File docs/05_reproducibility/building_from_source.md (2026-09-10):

# Building from Source

> [!NOTE]
> This guide assumes you have a working Python 3.13+ environment and are familiar with basic Python packaging and virtual environments. If you are new to Python packaging, consider reading the [Python Packaging User Guide](https://packaging.python.org/en/latest/).
>
> For developers who want to contribute to the project, we strongly recommend using editable installs (i.e., `pip install -e .`) for development. This allows you to make changes to the source code and have them reflected immediately without needing to rebuild the wheel each time. This guide is primarily for users who want to build the wheel for distribution or deployment, rather than for development purposes. Please refer to our [Development Guide](/CONTRIBUTING.md) for instructions on setting up a development environment and using editable installs.
>
> This guide works with any operating system that supports Python 3.13+, but the built wheel is only compatible with Raspberry Pi OS (64-bit) Bookworm or later. You can build the wheel on any platform, but it will only run on Raspberry Pi OS (64-bit) Bookworm or later. If you want to run the software on a different platform, you will need to modify the source code and build a compatible wheel for that platform.
>
> On Raspberry Pi OS (64-bit) Bookworm or later, you can use the prebuilt wheel instead of building from source. See [Setup Guide](./setup_guide.md) for instructions.

## Building the wheel

Clone the repository and navigate to the root directory:

```bash
git clone https://github.com/IaMaAVerYRANdOmPerSoN/WROFutureEngineer.git
cd WROFutureEngineer
```

Create a virtual environment and install the build dependencies:

```bash
python3 -m venv .venv # If you intend to test the built wheel, use --system-site-packages to access the system-installed picamera2
source .venv/bin/activate
pip install --upgrade pip build
```

Navigate to each namespace directory and build the wheel:

```bash
cd PiClient
python -m build piclient-core
python -m build piclient-open_challenge
python -m build piclient-obstacle_challenge
python -m build piclient-cli
```

You should now have a `dist` directory in each namespace with a built .whl (wheel) file, and a source distribution .tar.gz file! You can now install the wheel with pip:

```bash
# Return to the repository root to install all wheels
cd ..
pip install PiClient/*/dist/*.whl
```

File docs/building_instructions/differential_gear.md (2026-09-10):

# Differential Gear Assembly Instructions

All parts are 3D printed. Print everything before starting.

---

## Parts List

| Part | Quantity |
| ---- | --- |
| Crown Wheel | 1 |
| Large Gear | 2 |
| Small Gear | 2 |
| Big Spacer | 1 |
| Rotating Cage | 1 |
| Pinion | 1 |
| Rear Body Mount | 1 |
| 6mm Ball Bearing | 4 |
| T-joint Axle | 1 |
| Furitek Micro Komodo Motor | 1 |
| Screws (M2) | ~8 |

---

## `Step 1` Crown Wheel

Place the Crown Wheel flat with the bevel gear face pointing up. This is the base of the differential.

<p align="center">
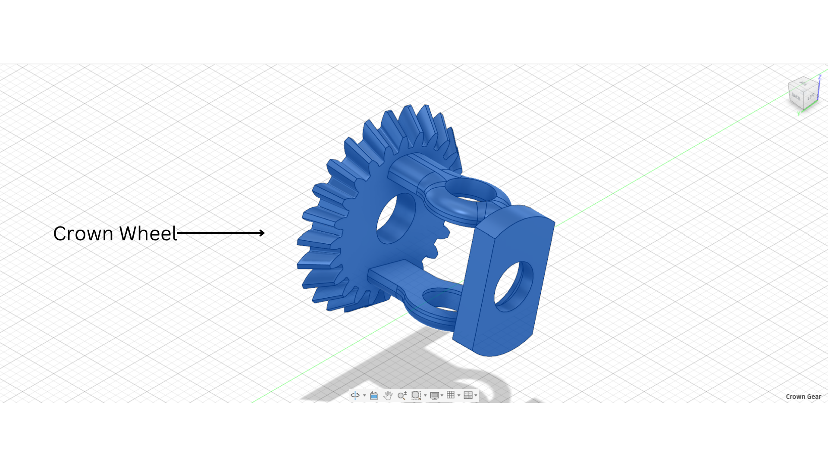
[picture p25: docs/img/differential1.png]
  
</p>
<p align="center"><i>Crown Wheel placed face up on work surface.</i></p>

---

## `Step 2` Insert Large Gears

Insert both Large Gears into the Crown Wheel. The longer shaft goes on the left, the shorter one on the right. Slide both through until seated.

<p align="center">
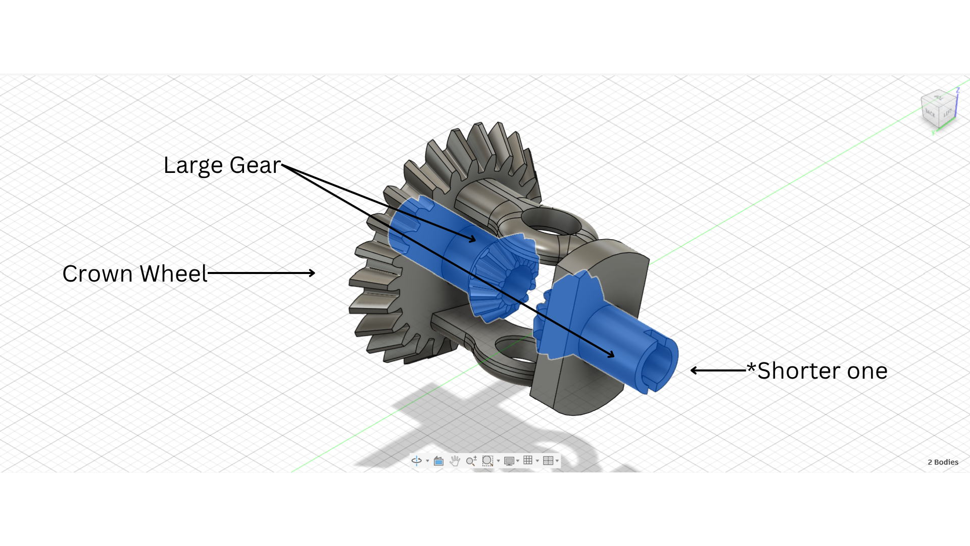
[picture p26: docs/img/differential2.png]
  
</p>
<p align="center"><i>Both Large Gears inserted — longer shaft on the left, shorter on the right.</i></p>

---

## `Step 3` Insert Small Gears

Push the Large Gears back slightly to make room, then insert the two Small Gears between them. Once in place, push the Large Gears forward to lock everything in.

<p align="center">
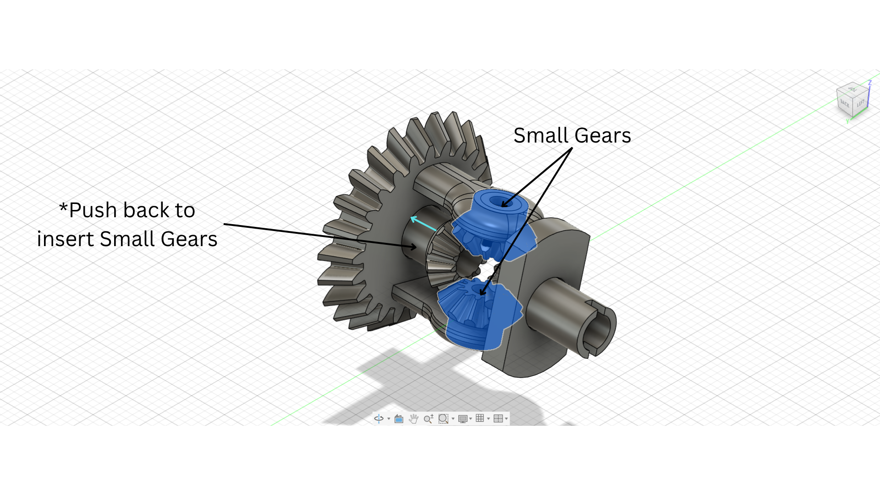
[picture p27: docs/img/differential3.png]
  
</p>
<p align="center"><i>Small Gears inserted between the Large Gears. Push Large Gears forward to lock.</i></p>

---

## `Step 4` Insert Big Spacer

Slide the Big Spacer onto the shaft from the front and push forward until it sits flush against the Crown Wheel. This holds the Small Gears in place.

<p align="center">
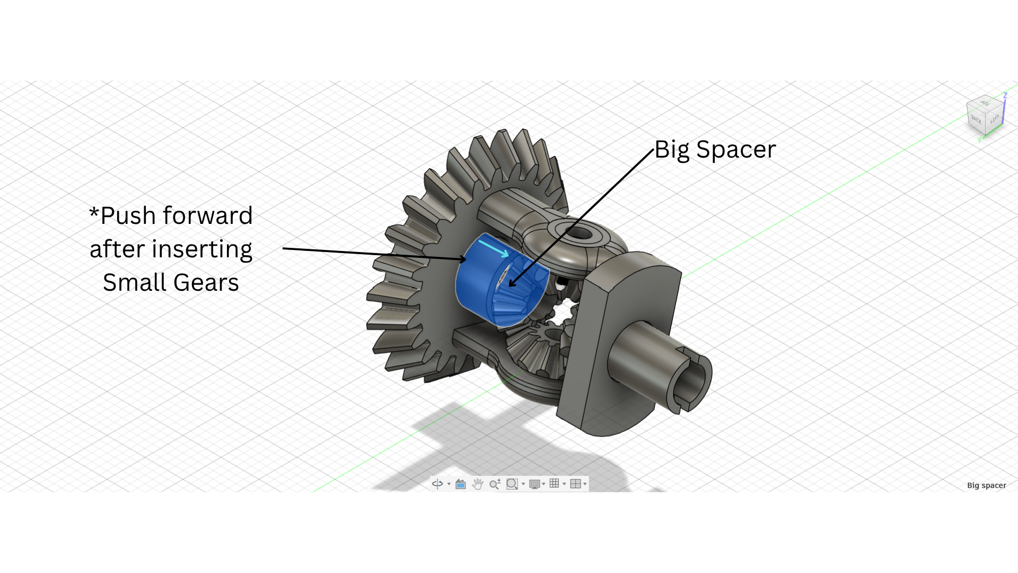
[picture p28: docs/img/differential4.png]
  
</p>
<p align="center"><i>Big Spacer pushed forward to secure the Small Gears.</i></p>

---

## `Step 5` Attach Rotating Cage

Slide both halves of the Rotating Cage onto the assembly from each side. Line up the holes and push in until fully seated.

<p align="center">
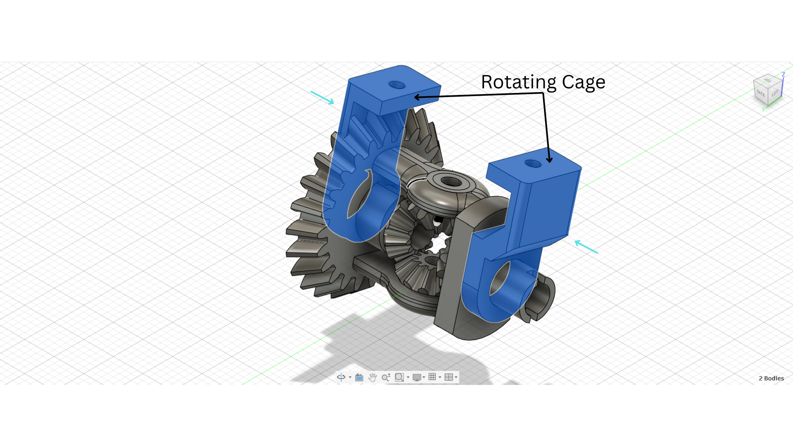
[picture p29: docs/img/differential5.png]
  
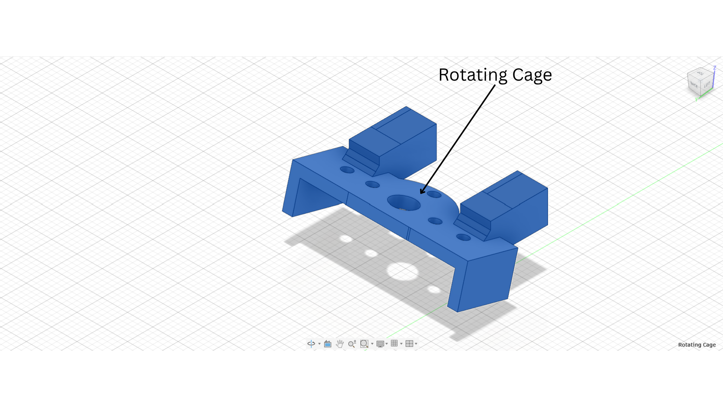
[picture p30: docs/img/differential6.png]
  
</p>
<p align="center"><i>Rotating Cage pressed onto both sides of the Crown Wheel assembly.</i></p>

---

## `Step 6` Mount the Motor

Place the motor into the mount bracket and screw in with M2 screws on both sides. The motor shaft should point down toward the Pinion position.

<p align="center">
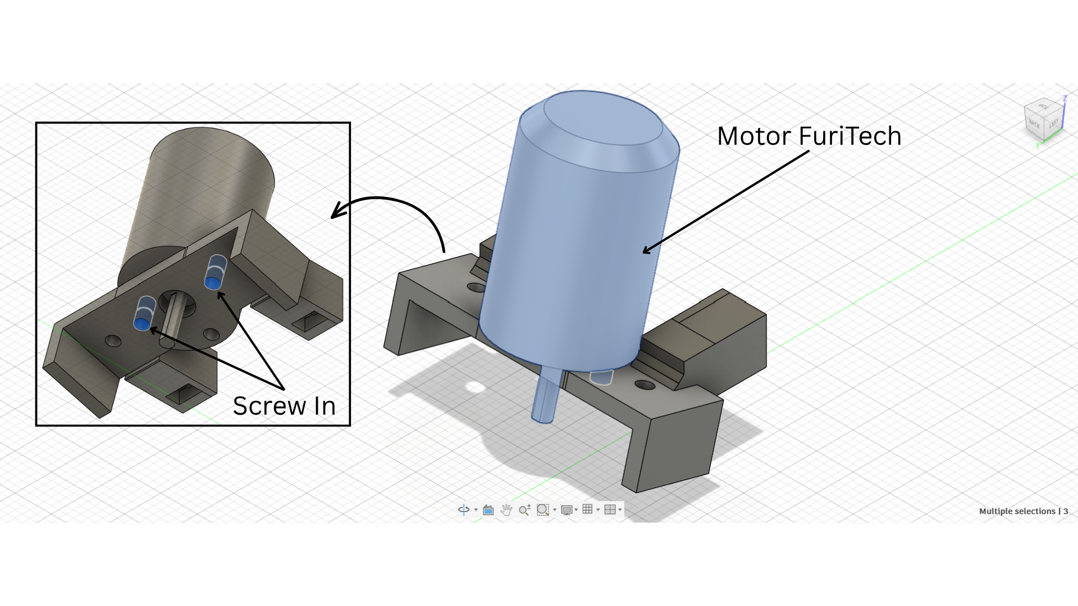
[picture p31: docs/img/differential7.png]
  
</p>
<p align="center"><i>Motor screwed into the mount bracket. Shaft pointing down.</i></p>

---

## `Step 7` Attach Pinion

Push the Pinion up onto the motor shaft from below until it meshes with the Crown Wheel teeth. Screw in through the side to secure it.

<p align="center">
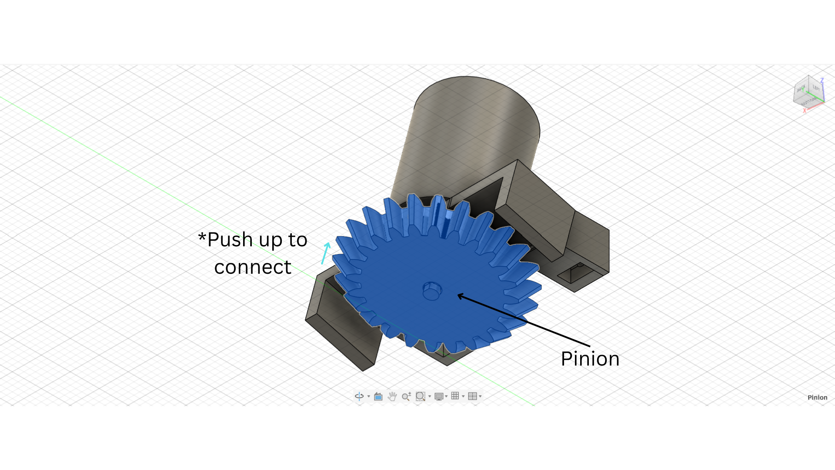
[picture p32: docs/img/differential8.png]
  
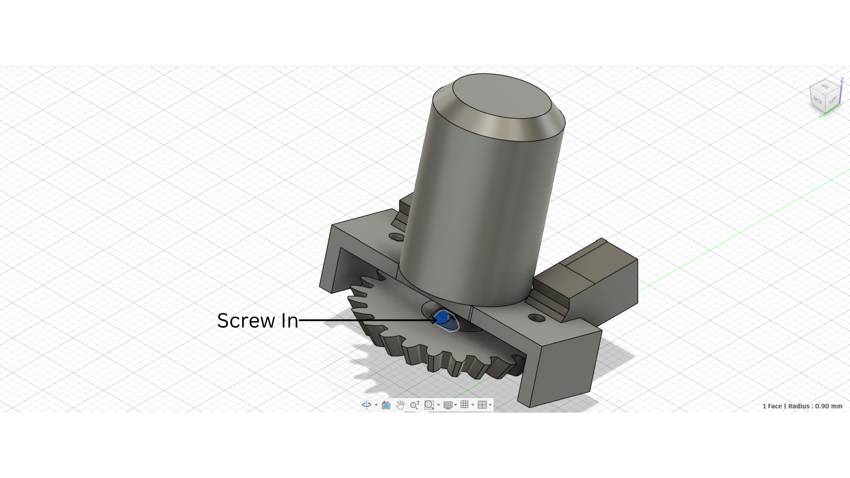
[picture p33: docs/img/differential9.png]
  
</p>
<p align="center"><i>Pinion pushed up onto the motor shaft and screwed in from the side.</i></p>

---

## `Step 8` Mount Motor Assembly to Rotating Cage

Push the motor and differential assembly down into the Rotating Cage. Line up the slots and press in until seated. Screw in through both sides.

<p align="center">
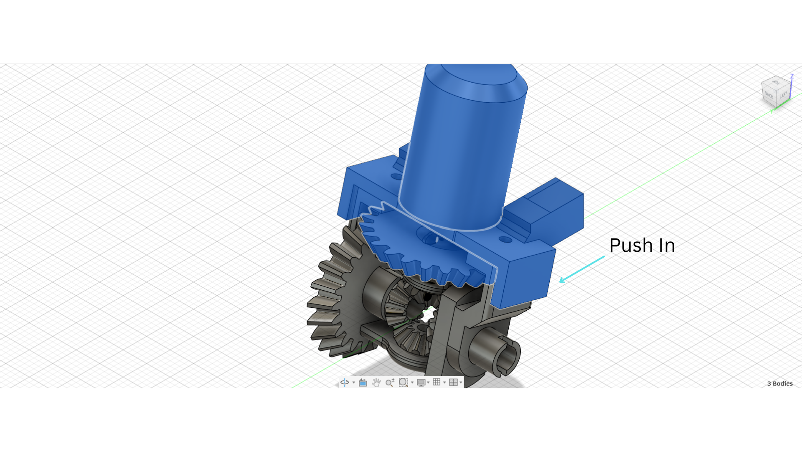
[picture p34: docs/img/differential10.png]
  
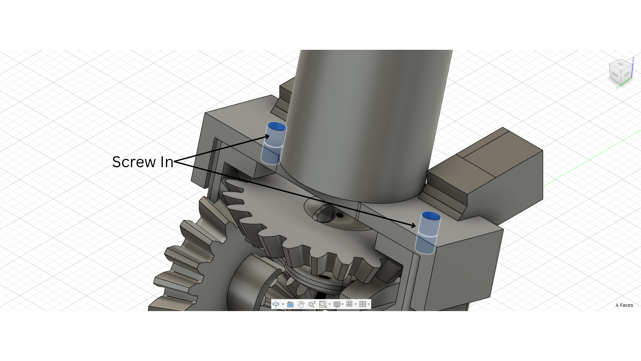
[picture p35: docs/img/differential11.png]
  
</p>
<p align="center"><i>Motor assembly pressed into the Rotating Cage and screwed down on both sides.</i></p>

---

## `Step 9` Prepare Rear Body Mount

Press four 6mm ball bearings into the bearing seats on the Rear Body Mount (two on each side). Insert the axle through each side.

<p align="center">
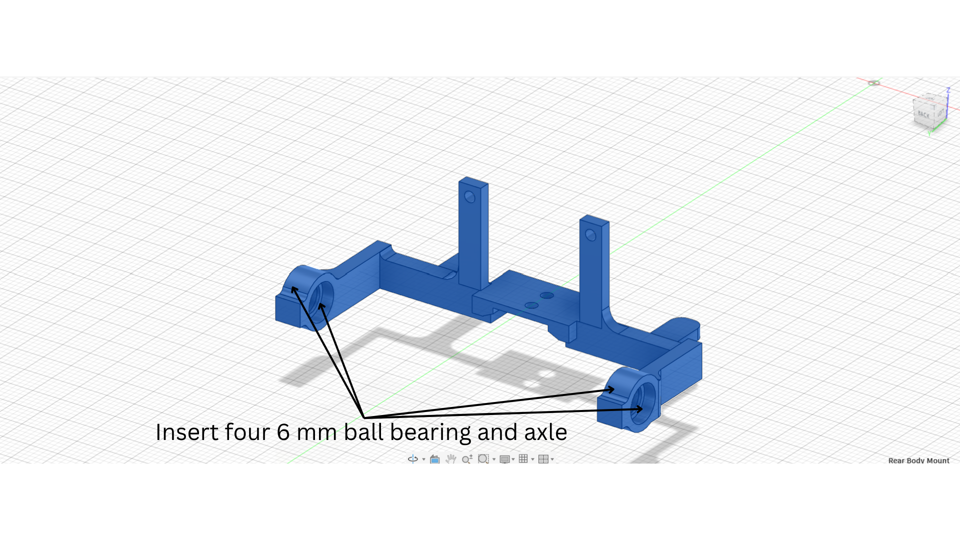
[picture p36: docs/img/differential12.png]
  
</p>
<p align="center"><i>Four ball bearings pressed into the Rear Body Mount with axles inserted.</i></p>

---

## `Step 10` Attach Wheels

Screw the wheels onto each axle. Make sure they are tight and do not wobble.

<p align="center">
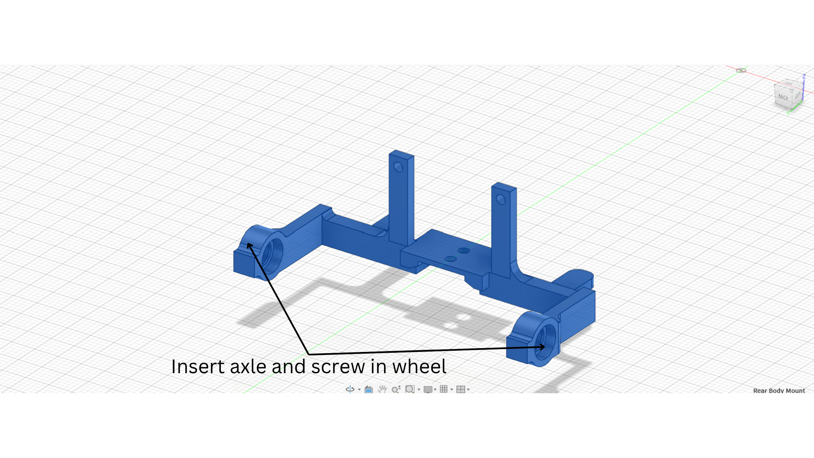
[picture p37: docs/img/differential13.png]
  
</p>
<p align="center"><i>Wheels screwed onto each axle.</i></p>

---

## `Step 11` Final Assembly

Push the full differential assembly down into the Rear Body Mount while inserting the T-joint axle through the Crown Wheel center. Screw into the Rear Body Mount through all mounting points.

<p align="center">
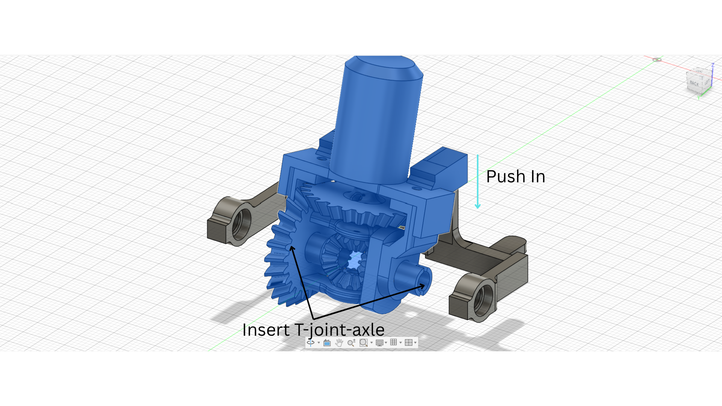
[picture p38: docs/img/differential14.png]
  
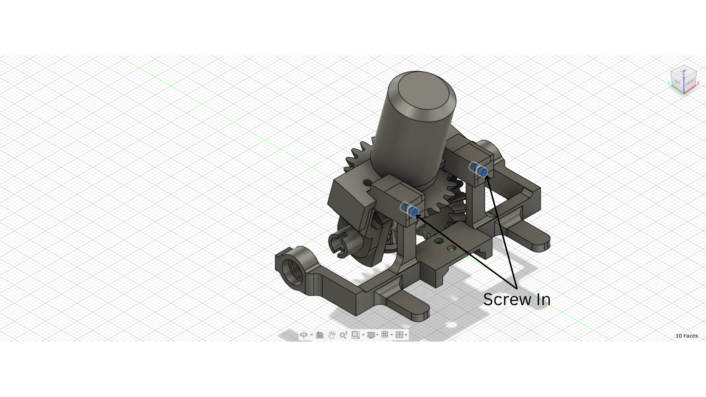
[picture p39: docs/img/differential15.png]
  
</p>
<p align="center"><i>T-joint axle inserted and full assembly screwed into the Rear Body Mount.</i></p>

---

## Check Before Installing

- Both wheels spin freely by hand.
- Holding one wheel still makes the other spin at double speed.
- No gears are skipping or binding.
- All screws are tight.

> **Note:** Do not hammer any parts together. The middle axle has broken in previous builds when too much force was used. Press by hand only.

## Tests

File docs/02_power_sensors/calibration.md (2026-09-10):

# Calibration

[Back to README](../../README.md)

## Why Calibration Is Needed

- **Lighting variation** : competition lighting differs from home/practice lighting, which shifts what raw camera values correspond to each color
- **Manufacturing/mounting variation** : the ESC's throttle response and the camera's mounting angle vary slightly unit to unit
- **Sensor drift** : none of our current sensors drift meaningfully over a match, but color thresholds "drift" in practice whenever the venue changes
- **Measurement consistency** : the PD controller and vision pipeline both assume their tuned constants match the physical robot; if they don't, steering and object detection degrade

---

## Sensors/Actuators That Require Calibration

| Sensor/Actuator | What Is Calibrated | Why |
|---|---|-----|
| OV5647 camera | Color thresholds (UV-plane ranges per color, Y-plane ranges for black/white) | Raw pixel values for "red," "green," etc. shift with lighting conditions |
| OV5647 camera | Perspective transform (bird's-eye homography) | Converts the angled camera view to top-down coordinates for real-world distance estimates |
| Furitek Lizard Pro ESC | Throttle endpoints | Matches the ESC's PWM input range to the Arduino's output pulse range so commanded throttle produces expected torque |
| Control loop | PD gains (wall-follow, corner-turn, obstacle-avoid) | Tuned to the robot's actual mass, speed, and steering response rather than a generic starting value |

---

## Calibration Procedure for Camera Color Thresholds

- **Purpose:** Make the vision pipeline reliably classify walls (black/white), corner lines (orange/blue), and pillars (red/green) under the lighting the robot will actually run in.
- **Tools required:** Raspberry Pi with camera connected, `PiClient/utils` interactive tuning tools, laptop/monitor to view output.
- **Setup:** Place the robot on the actual competition mat (or as close a lighting match as possible), with the field elements (walls, corner lines, pillars) in frame.
- **Steps:**
    1. From `PiClient/`, run `python -m utils --tool contours contourbinary` to view the live camera feed with detected contours overlaid, plus a binary "clean blob" view.
    2. Compare detected regions against the real field elements. Under- or over-detected colors indicate thresholds are too narrow or too wide.
    3. Edit the relevant threshold constants in [`PiClient/src/config.py`](../../PiClient/src/config.py) — `LOWER_BLUE`/`UPPER_BLUE`, `LOWER_ORANGE`/`UPPER_ORANGE`, `LOWER_GREEN`/`UPPER_GREEN`, `LOWER_RED`/`UPPER_RED` (UV-plane ranges), and `LOWER_BLACK`/`UPPER_BLACK`, `LOWER_WHITE`/`UPPER_WHITE` (Y-plane ranges).
    4. Re-run the tool and repeat until detections are clean and stable across the frame.
- **Parameters measured:** UV-plane min/max per color; Y-plane min/max for black/white.
- **Parameters saved:** Hardcoded as constants in `Config.VisionConfig` in `PiClient/src/config.py` — there is currently no separate config file or persisted calibration profile.
- **When calibration is performed:** Before competition runs, whenever venue lighting changes noticeably, or after any camera/lens change.

---

## Calibration Procedure for Perspective Transform

- **Purpose:** Convert the camera's angled view into a bird's-eye view so pixel distances approximate real-world distances.
- **Tools required:** Camera view of the mat with known reference points, `VisionProcessor.get_perspective_transform()`.
- **Setup:** Place reference markers at known real-world coordinates within the camera's field of view.
- **Steps:**
    1. Identify four (or more) reference points visible in the camera frame with known real-world positions.
    2. Compute the homography matrix using `VisionProcessor.get_perspective_transform()`.
    3. Set `Config.VisionConfig.PERSPECTIVE_TRANSFORM` in `PiClient/src/config.py` to the resulting matrix.
- **Parameters measured:** Pixel coordinates of reference points and their corresponding real-world coordinates.
- **Parameters saved:** 3x3 homography matrix in `Config.VisionConfig.PERSPECTIVE_TRANSFORM`.
- **When calibration is performed:** Currently **not performed** — `PERSPECTIVE_TRANSFORM` is still a placeholder of zeros. For Open Challenge, wall-following only needs relative left/right wall distance, not true metric distance, so the current plan is to bypass this transform for Open Challenge rather than spend time calibrating it. It remains open for Obstacle Challenge if metric distance estimation becomes necessary.

---

## Calibration Procedure for ESC Throttle Range

- **Purpose:** Match the Furitek Lizard Pro ESC's expected PWM pulse range to the pulse range the Arduino actually outputs, so a given throttle command produces consistent, expected torque.
- **Tools required:** Furitek Lizard Pro ESC, Arduino Uno R3, battery, motor.
- **Setup:** Motor and battery connected, robot safely elevated so wheels can spin freely.
- **Steps:**
    1. Follow the ESC manufacturer's calibration procedure (typically: power on with throttle at max, then min, to record endpoints).
    2. Verify the neutral/stop pulse (1500µs, per [`ArudinoServer/src/main.cpp`](../../ArudinoServer/src/main.cpp)) is recognized as "stop" by the ESC.
    3. Test throttle at the operating range used in code (30-40%, per [torque_speed_reasoning.md](../01_mechanical/torque_speed_reasoning.md)) and confirm torque output matches expectations.
- **Parameters measured:** Min/max/neutral PWM pulse widths recognized by the ESC.
- **Parameters saved:** Stored internally by the ESC itself (not in our codebase). The Arduino firmware's output range must stay within what the ESC was calibrated to accept.
- **When calibration is performed:** After any ESC replacement or reset, or if throttle response feels inconsistent with commanded speed. An uncalibrated ESC previously caused a loss of torque at expected throttle values.

---

## Calibration Procedure for PD Controller Gains

- **Purpose:** Tune steering response (wall-following, corner-turning, obstacle-avoidance) to the robot's actual handling characteristics.
- **Tools required:** Assembled robot on the track, `PiClient/utils` control diagnostics tool.
- **Setup:** Robot placed on a straight or cornered section of track matching the behavior being tuned.
- **Steps:**
    1. Run `python -m utils --tool control` to view a live overlay of the current P/D values for each mode.
    2. Run the robot and observe steering behavior (oscillation, overshoot, sluggish correction).
    3. Adjust `WALL_FOLLOW_KPKD`, `CORNER_TURN_KPKD`, and `OBSTACLE_AVOID_KPKD` in `Config.OpenChallengeConfig`/`Config.ObstacleChallengeConfig` in `PiClient/src/config.py`.
    4. Re-test until steering is stable without excessive oscillation.
- **Parameters measured:** Qualitative steering behavior (oscillation, response lag).
- **Parameters saved:** `(Kp, Kd)` tuples per mode, hardcoded in `PiClient/src/config.py`.
- **When calibration is performed:** After any change to robot weight, wheel/tire grip, gear ratio, or speed settings.

---

## Example Calibration Results

| Sensor | Parameter | Before | After | Notes |
|---|---|---|---|---|
| Camera | Green pillar UV threshold | Detected under indoor fluorescent light only | Widened range to also catch competition venue lighting | Re-tuned on-site before competition |
| ESC | Throttle response | Torque loss at expected throttle values | Full expected torque restored | Root cause was a missed ESC calibration step, not a code issue |

---

## Calibration Storage

- **Where calibration values are stored:** Directly as hardcoded constants in [`PiClient/src/config.py`](../../PiClient/src/config.py) (`Config.VisionConfig`, `Config.OpenChallengeConfig`, `Config.ObstacleChallengeConfig`). ESC endpoint calibration is stored internally by the ESC hardware itself.
- **How they are loaded:** Imported directly as Python class attributes wherever `Config` is used — no external config file is read at runtime.
- **How calibration is verified:** Visually, using the `utils` diagnostic tools (`contours`, `contourbinary`, `control`) before a run. There is currently no automated verification or saved calibration profile, this is a known gap.

---

## Common Calibration Issues

- Thresholds tuned indoors under one lighting setup don't transfer to competition lighting
- Corner line and pillar colors can look similar under certain lighting if thresholds are too wide
- An uncalibrated ESC silently reduces torque without any error, it can look like a code or gearing problem
- PD gains tuned for one speed setting can cause oscillation if speed is changed later without re-tuning
- No persisted calibration file means values can be accidentally overwritten or lost if `config.py` changes are not tracked carefully

---

## Final Notes

All current calibration is manual: thresholds and gains are tuned by eye against a live camera/diagnostic overlay and then hardcoded into `config.py`, rather than measured and saved through an automated or file-based calibration step. This is fast to iterate on but fragile, it must be redone at every venue with different lighting, and there's no way to verify at startup that the robot is still correctly calibrated. Formalizing this (e.g., a saved calibration file loaded at startup, with a quick on-site verification routine) is a planned improvement.

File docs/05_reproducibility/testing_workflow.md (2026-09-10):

# Testing Workflow

Because trivial unit tests cannot replicate real-world traction, dynamic lighting, or sensor noise, our testing workflow treats track time as the SSOT (Single Source of Truth). The track is the only environment that accurately represents the real-world conditions that the robot will face during competition. While we have a comprehensive unit and integration test suite, no change is considered valid until it has been validated on the track. This ensures that our robot performs reliably under the conditions it will encounter during competition.

## Hardware Testing

Our hardware is validated directly on the robot. Running the robot on the track allows us to test the mechanical and electrical systems in a real-world environment. We perform a series of tests to ensure that all components are functioning correctly and that the robot can navigate the track as expected before committing to any changes. This includes testing the motors, sensors, and other hardware components to ensure they are working as intended.

The fast iteration cycle of 3D printing allows us to quickly prototype and test new parts. We can print a new part, install it on the robot, and test it on the track within a short period of time. This rapid prototyping process enables us to make improvements and adjustments to the hardware design based on real-world testing results. Since the hardware design is not under version control, we always make sure to keep past versions of the hardware in case we need to revert to a previous design. This allows us to change back to a previous design if a new design does not perform as expected or introduces new issues, without high opportunity cost.

Electronics are first tested in a SPICE simulation environment to validate the circuit design before being implemented on the robot. This allows us to catch any issues with the circuit design before they are implemented in hardware, which can save time and resources. Once the circuit design is validated in simulation, we implement it on the robot and test it on the track to ensure that it functions as expected in a real-world environment.

We use electronics from reputable manufacturers to ensure that the components are reliable and perform as expected. This reduces the risk of component failure during testing and competition, which can be costly and time-consuming to fix. We also perform a series of tests on the electronics to ensure that they are functioning correctly and that they can withstand the conditions of the track.

## Software Testing

Our software testing is largely automated by our CI/CD pipeline. Since some integration/system tests are impossible without a real robot and track, we focus on unit tests and integration tests that can be run in a simulated environment. This allows us to catch issues early in the development process and ensure that our code is functioning correctly before it is deployed to the robot.

All pull requests and commits to the main branch are automatically tested by the CI/CD pipeline. This ensures that any changes to the codebase are thoroughly tested and validated before they are merged into the main branch. The automated testing process helps us maintain a high level of code quality and reduces the risk of introducing bugs or issues into the system.

We also ensure all our tests are reproducible and deterministic. This means that the tests should produce the same results every time they are run, regardless of the environment or conditions. This is important for ensuring that our tests are reliable and that any issues can be consistently reproduced and addressed.

In addition to automated testing, we also perform manual testing on the robot to validate the software in a real-world environment. This includes running the robot on the track and observing its behavior to ensure that it is functioning as expected. Any issues or unexpected behavior are documented and addressed through further testing and development. If the robot fails to complete a run, we analyze the logs and video footage to identify the root cause of the failure. This information is used to make improvements to the software and hardware design, which are then tested again on the track.

Our CI/CD pipeline also includes automated documentation generation and deployment, which ensures that our public API documentation is always up-to-date with the latest code changes. This allows us to maintain accurate and comprehensive documentation for our system, which is important for both internal development and external collaboration.

## Production Fallback Plan

We always have a fallback plan in case of hardware or software failure during testing or competition. This includes having spare parts and components on hand, as well as a backup version of the software that can be deployed to the robot if necessary. We also maintain a detailed log of all changes made to the hardware and software, which allows us to quickly identify and address any issues that arise:

- All software changes are tracked in a version control system (Git) with detailed commit messages and pull request descriptions.
- All packages are uploaded to PyPI, which allows us to easily install a precompiled wheel of the software on the robot in case of a failure. This allows us to quickly revert to a known working version of the software if necessary,
perform disaster recovery during competition, and maintain a stable and reliable system throughout the development process.
- All electronics and mechanical components are labeled and organized, which allows us to quickly identify and replace any faulty components during testing or competition. Catastrophic electronic failures cannot be mitigated during a competition, so we always have a fully assembled electronics backup ready to swap in if a failure occurs. This allows us to quickly recover from any hardware failures even when under strict time constraints.
- We maintain a strict policy of at least 2 spares of each critical component, which allows us to quickly replace any faulty components during testing or competition. This ensures that the robot can continue to operate effectively even in the event of a hardware failure.

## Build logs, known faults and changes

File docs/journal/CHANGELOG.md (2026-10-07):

# WRO Future Engineers 2026

# Journal

## Week 1 (Dec 22–28)

- GitHub repository created.
- Async RPC implemented between PiClient and ArduinoServer.
- Async PiCamera2 wrapper created; obstacle detection and field boundary checking developed.

---

## Week 2 (Dec 29–Jan 5)

- Main file and template test file created; API documentation started.
- Multiprocessing implemented across three processes; obstacle avoidance logic built; AsyncVisionProcessor calls simplified.
- Tests directory created; camera unit tests run.

---

## Week 3 (Jan 6–12)

- Motor and servo libraries added; AsyncCamera resolution increased; CommProtocol max speed adjusted.
- AsyncCamera and VisionProcessor refactored; multiprocessing added for camera and vision.
- Shopping list added.

**Python Packaging Iterations**

| Version | Design Goals | Limitations | Takeaways |
| --- | --- | --- | --- |
| 1 | No packaging, just a single src directory with module-level imports. | Isolation of concerns suffered; architecture became tightly coupled without clear interfaces. | A single src directory is not a sustainable architecture for a project of this scope. |
| 2 | Independently maintain a simpler src_min implementation, forgoing complex multiprocessing and async IO. | The simple implementation does not meet performance constraints, and maintaining two implementations adds significant burden. | A simpler, slower implementation was a trade-off the team could not accept given latency and throughput requirements. |
| 3 | Use multiple sub-packages within a single src directory. | Architecture still tightly coupled; sub-packages not easily reusable or distributable. | Sub-packages are a step in the right direction but do not provide enough isolation of concerns. |
| 4 | Adopt a namespace package architecture with multiple sub-packages, each with distribution metadata and clearly defined exports. | Complex packaging requirements requiring deep understanding of Python packaging and distribution. | Namespace packages provide a sustainable architecture with clear interfaces and independently distributable components. |

The final namespace package architecture was adopted because the multi-process producer-consumer pipeline required clearly defined interfaces between the camera, vision processor, state machine, and hardware interfaces to avoid untraceable race conditions and shared memory allocation failures.

> For more details see [Iteration Cycles](../04_systems_engineering/iteration_cycles.md).

---

## Week 4 (Jan 13–19)

- WRO Future Engineers 2026 rules released.
- Component search began.
- Fusion 360 prototype created.

---

## Week 5 (Jan 20–26)

- First KiCad schematic draft completed.
- Footprints, symbols, and labels added to KiCad library.
- PCB routing started.
- Steering PWM fixed; vision.py entry point added.

---

## Week 6 (Jan 27–Feb 2)

- First 3D print of chassis completed.

---

## Week 7 (Feb 3–9)

- STEP file added for initial prototype.
- Logging, shared memory, and plan.md refactored.

---

## Week 8 (Feb 10–16)

- Wheels purchased.

---

## Week 9 (Feb 17–23)

- Physical robot assembly began.

---

## Week 10 (Feb 24–Mar 2)

- Servo and drive motor functioning together.
- New differential gear assembly created.
- Documentation outline created.

**Mechanical Iterations — First Versions**
The first versions of all 3D printed parts were adapted from last year's robot. Key changes made at this stage:
- Turning system reused directly; steering horn breakage identified as a recurring issue.
- RP5 layout rotated and made slimmer; camera positioned high and angled downward.
- Arduino Uno layout updated with correct mounting holes and a rectangular cutout to reduce filament.
- Connectors introduced at medium length to replace brass standoffs and speed up assembly.

> For more details see [Mechanical Iterations](../01_mechanical/mechanical_iterations.md).

---

## Week 11 (Mar 3–9)

- Online differential design failed under load.
- First custom differential failed structurally during testing.
- Second reinforced differential designed and printed.

---

## Week 12 (Mar 10–16)

- Camera error encountered.

---

## Week 13 (Mar 17–23)

- Camera error persisting.
- Multiprocessing bugs fixed; memory leak checks added.
- Project structure refactored; async vision processing implemented.
- Async vs multiprocessing architecture decision made: overlapping only helps when capture + processing time exceeds the frame interval.

---

## Week 14 (Mar 24–30)

- Camera intermittent; root cause unknown.
- Deans-T connector melted; replaced.
- First draft of open challenge code completed.
- Obstacle challenge code started.
- Arduino code reviewed; issues identified.
- General bugfix pass done.

---

## Week 15 (Mar 31–Apr 6)

- Coach flagged differential ground clearance issue.
- Coach reviewed open challenge code - [see full review](../coach_comments.md#april-15th).
- LiDAR placement under discussion.
- Camera confirmed as hardware fault - I2C error on OV5647; replacement camera borrowed.
- Off-the-shelf differential explored as backup.
- 20A power switch sourced and installed.
- Motors confirmed spinning at 30% throttle.

---

## Week 16 (Apr 7–13)

- LiDAR mount printed and installed; chassis raised to accommodate.
- Robot confirmed able to scan walls and obstacles.
- Differential middle axle broke; reprinted but still dragging on ground.
- Switched to smaller power switch.
- Voltage regulator mount created.
- Code refactored; utilities package added; coach review requested.
- Vision pipeline partially working; color thresholds need tuning.
- Camera and servo half working.

---

## Week 17 (Apr 14–20)

- Coach removed Hybrid state from open challenge; simplified to two states.
- Fixed oscillation bug between Turn and Follow Wall states using hysteresis.
- Updated and pushed open_challenge.py.

---

## Week 18 (Apr 21–27)

- Differential melted from running too fast; reprinted and upgraded.
- Reflashed SD card but still could not connect; Raspberry Pi confirmed broken.

---

## Week 19 (Apr 28–May 4)

- Differential still not working; decided to buy one if not fixed by next week.
- Voltage regulator short circuited; port broke.

---

## Week 20 (May 5–11)

- Differential fixed and working.
- Voltage regulator repair in progress.

---

## Week 21 (May 12–18)

- Fixing open challenge issues.

---

## Week 22 (May 19–25)

- Open challenge still in progress.
- Most time spent on exams.

---

## Week 23 (May 26–Jun 1)

- Primary coder left for China; difficulty navigating code through RealVNC.
- Differential broke again.

---

## Week 24 (Jun 2–8)

- PD values poorly tuned; robot crashing into inner walls.
- Lap counting still an issue.
- Open challenge completed.
- Wire to motor disconnected; re-soldered.

---

## Week 25 (Jun 9–15)

- Motor gear wearing out after 1-2 days; taped as temporary fix.
- Corner turn PD biasing proposed.
- PCB shipped to Toronto.
- Config system updated to support TOML file overrides.

---

## Week 26 (Jun 16–22)

- Vision and open challenge code updated with new tuning values; confirmed working.
- Obstacle challenge testing started; obstacles excluded during preliminary testing.

---

## Week 27 (Jun 23–29)

- Obstacle challenge code completed and ready to test.
- Test video recorded by pushing robot by hand; replay system working without needing the physical robot.
- Bug found in obstacle challenge; fix not yet identified.
- Coach noted walls need to be flipped to avoid glare affecting detection.
- VS Code extension host crashing due to Pylance using 1.7GB RAM; no easy fix.
- Bug identified: robot drives sideways despite correct steering indicator; likely a feedback loop from incorrect state entry.
- Coach found wall distances appear swapped and angle direction may be inverted in the vision output.
- Steering gimbal snapped again.
- Camera confirmed at maximum 62.50 fps at 640x480.
- Raspberry Pi Camera Module 3 Wide researched as upgrade (supports 120 fps).
- Extra battery requested from coach.

---

## Week 28 (Jun 30–Jul 6)

- Red pillar color encoding bug found (BGR/RGB mix-up); pillar detection showing progress.
- Differential dragging on the floor again.
- Decided to buy an off-the-shelf differential instead of continuing with the custom printed design.
- Team member away until Monday.

---

## Week 29 (Jul 7–13)

- Purchased differential arrived but was too large and hit the ground during testing.
- Contacted coach to source a smaller alternative rather than modifying wheels or chassis.
- Robot moving but still a little clanky.
- Checked WRO rules on robot size changes; no rule against it, but robot cannot touch the parking lot walls.
- Explored using last year's parking strategy on a different wall instead of parallel parking.

---

## Week 30 (Jul 14–20)

- Length-extending attachments cancelled.
- Coach found axle connectors too loose for differential output; lifting gearbox would cause new issues.
- Coach provided a smaller differential gearbox from an old RC kit that may fit the existing axles.
- Plan to design two 3D printed parts: gearbox mount and motor-to-shaft connector.
- Measurements and photos of gearbox taken and shared with hardware team member.
- Gearbox confirmed 22mm tall; design work started.

---

## Week 31 (Jul 21–27)

- New gearbox mount designed and printed.
- Parallel parking FSM completed.
- Fusion 360 source file requested to edit mount design; updated STEP file sent for printing.
- Checked WRO rules on parking lot stick height; no official ruling found. Coach advised proper parallel parking is required.
- Wiring broke; re-soldered.

---

## Week 32 (Jul 28–Aug 3)

- Raspberry Pi showing error code 4 long 3 short (RP1 not found); confirmed dead. Burning smell noticed days prior.
- Backup Pi picked up from coach's mailbox and set up. Fan configured to always run to prevent overheating.
- Differential no longer dragging but motor does not have enough torque; spins but cannot move the robot after sharp turns.
- Likely cause is too much gearbox friction or gears slipping under load.
- Coach suggested updating ESC speed values for the new gear ratio and calibrating the ESC using the FuriCar app.
- Speed constants already updated; camera frame rate limit of 62.5 fps is now the speed ceiling.
- Root cause of torque issue still unknown; coach suggested trying the previous motor.

---

---

## Week 33 (Aug 4–10)

- CI pipeline fixed; API reference deployments now automated and testing CI working correctly.
- API docs live at https://apostla-api-reference.web.app/index.html. TestPyPI deployment planned as next step.

---

## Week 34 (Aug 11–17)
 
- Parking lot wall following issue identified - parking lot blocks view of wall for a few seconds causing erratic behaviour. Coach suggested maintaining orientation for a fixed duration when wall is temporarily obscured.
- Steering gimbal broke again; ran out of backup parts. Requested more extras to be printed.
- Servo stopped working entirely despite correct wiring. First time this servo has failed. No backup available - looking for a fast replacement online.
---
 
## Week 35 (Aug 18–24)
 
**Mechanical Iterations**
- Turning system V3: curved front bumper added to allow robot to slide off walls in obstacle challenge instead of getting stuck.
- Arduino layout V3: servo moved rearward to shorten robot length; front section extended to support bumper attachment.
- Connectors V3: shortened to C-shape to keep robot compact while routing around the battery.
> For the full version history of all printed parts see [Mechanical Iterations](../01_mechanical/mechanical_iterations.md).
 
**Differential Gear Iterations (Versions 4-5)**
 
| Version | Design Goals | Limitations | Takeaways |
| --- | --- | --- | --- |
| 4 | Use a robust metal differential designed for RC cars. | The differential was too large for the universal axles, rubbed against the floor, and bent the rear assembly because of its weight. | Components cannot be viewed in isolation; they are constrained by and must be viewed in the context of the entire system. |
| 5 | Use a compact differential gearbox salvaged from a smaller RC car (1/24-1/28). | The gearbox was salvaged rather than purpose-built. No backups available, and the design is not easily reproducible. | The smaller, lighter, self-contained gearbox eliminated 3D-printed gears, reduced complexity, fit the design constraints, and allowed the robot to run smoothly. |
 
> For more details see [Iteration Cycles](../04_systems_engineering/iteration_cycles.md).
 
- Switched differential with one from an RC car (1/4 gear ratio)

---

## Week 36 (Aug 25–31)

- Servo ordered from RobotShop via Xpress Post.
- New differential gearbox confirmed working correctly.
- New servo received and picked up.
- First draft of the assembly animation completed, still rough.

---

## Week 37 (Sep 1–7)

- All new printed parts finished - assumed to be the final hardware design.
- Turning system, RP5 layout, Arduino Uno layout, and connector iterations documented and added to the repo.
- Current differential confirmed as a pre-built off-the-shelf unit.
- Voltage regulator identified - Yahboom buck converter (6V–24V to 5V/5A) designed specifically for Raspberry Pi 5.

## Week 38 (Sep 7–13)

- Began switching the main microcontroller from the Arduino Uno R3 to an Arduino Nano.
- New 3D-printed mounts designed so the Nano fits on the chassis in place of the Uno.

## Week 39 (Sep 14–20)

- Nano installed on the robot using the new mounts.
- LiDAR mount designed and printed.
- Decided not to use the LiDAR.

## Week 40 (Sep 21–27)

**Mechanical Iterations**
## Week 40 (Sep 21–27)

- Microcontroller code ported from the Uno to the Nano.
- Started reading heading data from the Nano's built-in IMU.

**Mechanical Iterations**
- Turning system V4: front bumper upgraded.
- Arduino layout V4: redesigned around the Arduino Nano, which takes up much less space than the Uno.
- Power switch mount V1: dedicated mount added so the switch is held securely instead of loose in the chassis.
- Overall design condensed, making the robot more compact and freeing up internal space.
> For the full version history of all printed parts see [Mechanical Iterations](../01_mechanical/mechanical_iterations.md).

---

## Week 41 (Sep 28–Oct 4)

- IMU heading readings were inconsistent.
- Cause found: `Serial.printf("Heading: %f\n", heading);` does not format floats correctly on the Nano, so the printed values were wrong. The IMU itself was working.
- Replaced it with `Serial.print("Heading: "); Serial.println(heading);`. Heading readings are now consistent.
---

## Major Problems
 
### 1. Differential Gear
 
- Online differential design failed under load ([Week 11](#week-11-mar-39))
- First custom design broke during testing ([Week 11](#week-11-mar-39))
- Middle axle broke during assembly ([Week 16](#week-16-apr-713))
- Melted from running the robot too fast ([Week 18](#week-18-apr-2127))
- Continued dragging on the ground after reprinting ([Week 16](#week-16-apr-713))
- Still not working after multiple iterations ([Week 19](#week-19-apr-28may-4))
- Fixed then broke again ([Week 20](#week-20-may-511), [Week 23](#week-23-may-26jun-1))
- Gear connecting to motor wears out after 1-2 days ([Week 25](#week-25-jun-915))
- Purchased off-the-shelf differential was too large and hit the ground; sourced a smaller gearbox from coach's old RC kit ([Week 28](#week-28-jun-30jul-6), [Week 29](#week-29-jul-713), [Week 30](#week-30-jul-1420))
- Axle connectors too loose for the differential output ([Week 30](#week-30-jul-1420))
- Axle slipping in the differential gearbox ([Week 32](#week-32-jul-28aug-3))
- Switching differential ([Week 35](#week-35-aug-1824))

The differential was the single biggest hardware headache all build. Honestly the part that got us down the most. The team started with an adapted online design which failed right away under load because the teeth didn't mesh properly. Three custom printed versions came after that, each one fixing a different problem, bad tooth shape, axle slipping, and too much friction from the 3D printing itself. After the third printed one melted from heat at high speed, we decided to just buy an off-the-shelf differential instead. The first one we bought was too big and dragged on the ground. Instead of changing the chassis, the coach found a smaller gearbox from an old RC car kit that fit our axles and had a better gear ratio, which finally fixed it and the robot ran smoothly. Every failure pushed us to a different fix, and we learned that you can't look at one part on its own, everything on the robot affects everything else. Looking back it's kind of funny that months of work came down to one small gearbox from the coach's old RC kit.
 
### 2. Camera
 
- Error persisted for three weeks ([Week 12](#week-12-mar-1016), [Week 13](#week-13-mar-1723))
- Confirmed hardware fault - I2C error on OV5647 sensor; resolved by borrowing a replacement ([Week 15](#week-15-mar-31apr-6))

The camera stopped working during testing and the cause was clear at first. We assumed it had to do something with the software or configuration. After a lot of debugging including re-seating the CSI ribbon cable multiple times, checking config.txt overlays, and re-imaging the OS with no change, we finally figured out it was a hardware fault. The dmesg output showed an I2C read error on the OV5647 sensor (error -121) and the I2C bus at address 0x36 was completely empty, confirming the sensor itself had failed. Later that week, a replacement camera was borrowed from a teammate.
 
### 3. Raspberry Pi
 
- First Pi broke for unknown reasons ([Week 18](#week-18-apr-2127))
- Second Pi broke - LED error code 4 long 3 short (RP1 not found), unknown cause ([Week 32](#week-32-jul-28aug-3))

We went through two Raspberry Pi 5 units during the build. The first failed after a connection issue that could not be resolved even after reflashing the SD card. The second showed LED error code 4 long 3 short, meaning a hardware-level failure of the main I/O chip. We noticed a burning smell days before the second failure, so it was probably caused by a power event or short circuit. Both times the coach had a backup unit available which allowed us to continue. Now the fan is configured to always run on the replacement unit to reduce the risk of thermal damage.
 
### 4. Power System
 
- Deans-T connector melted ([Week 14](#week-14-mar-2430))
- Voltage regulator short circuited; port broke ([Week 19](#week-19-apr-28may-4))
- Wiring broke and required re-soldering ([Week 31](#week-31-jul-2127))
- Servo failed completely; no backup available ([Week 34](#week-34-aug-1117))

The power system broke down a bunch of times througout the build. The Deans-T connector melted early on because of undersized wiring carrying more current than it was rated for. We later replaced all wiring with correctly rated wire after. The step-down voltage regulator later short circuited when wires were caught in the motor system, breaking the regulator port entirely. The wiring to the motor also disconnected during testing and had to be re-soldered. Also, late in the build the servo motor failed completely for the first time, with no clear cause. We ordered a replacement via express shipping and it arrived within a few days.
 
### 5. Open Challenge Code
 
- Unnecessary Hybrid state and oscillation bug between Turn and Follow Wall states ([Week 17](#week-17-apr-1420))
- PD values poorly tuned; robot crashed into inner walls ([Week 24](#week-24-jun-28))
- Lap counting issues ([Week 24](#week-24-jun-28))

The first version of the open challenge code had a Hybrid state on top of Follow Wall and Turn, which was intended to handle the transition zone at corners. Our coach said it was unnecessary and pointed out it created 6 possible state transitions instead of 2, making the logic much harder to debug. We then removed and replaced it with a simpler two-state machine using hysteresis to prevent oscillation between states. The PD tuning proved difficult without consistent hardware and the robot frequently crashed into inner walls when switching states because the gains were set too aggressively. Lap counting was also unreliable because single-frame detections of the corner line were being counted multiple times. These issues were resolved through careful tuning on the track over several weeks.
 
### 6. Obstacle Challenge
 
- Robot driving sideways despite correct steering indicator ([Week 27](#week-27-jun-2329))
- Wall distances appearing swapped in vision output ([Week 27](#week-27-jun-2329))
- Color encoding bug causing wrong pillar colors in replay ([Week 28](#week-28-jun-30jul-6))
- Steering gimbal broke multiple times ([Week 27](#week-27-jun-2329), [Week 34](#week-34-aug-1117))

Working on the obstacle challenge turned up a bunch of bugs that would've been almost impossible to find without the replay system. The robot was driving sideways even though the steering indicator showed it going straight, which the coach figured out meant the left and right wall distances were swapped in the vision output, so the robot was steering the wrong way without knowing it. There was also a color bug where red pillars showed up as the wrong color in the replay because of a BGR/RGB mix-up in the code. The steering gimbal kept breaking from the sharp corrections during obstacle avoidance, so we had to reprint it more than once. We worked through all of it using the video replay system, which let us figure out problems without needing the actual robot running. This was probably the most confusing stretch of debugging all year, none of the robot's behavior made sense until the replay let us actually see what the vision was doing.
 
---
 
# Reflection
 
## What Could Have Been Done Better
 
### Hardware
 
We should have started with an off-the-shelf differential from the very beginning, because five rounds of printing our own cost us months of build time we didn't need to lose. The PLA material limits were a risk we should have seen coming a lot earlier than we did. We also should have kept more spare parts on hand from the start, since running out of steering gimbals and having no backup servo during important testing weeks cost us a lot of time we couldn't get back. Better cable management and strain relief from day one would have stopped the melted connector, the short-circuited regulator, and the motor wire coming loose. We also should have tested each component on its own before putting it all together, since the camera issue dragged on for three weeks partly because we didn't isolate it fast enough.
 
### Software
 
The codebase got over-engineered early on with async processing, multiprocessing, and shared memory before we even had basic wall-following working reliably, and getting something simple working first would have saved us a lot of debugging time later. HSV threshold tuning should have been standardized much earlier with a proper tool and documented values instead of being redone informally almost every session. The obstacle challenge also got started too late compared to the competition timeline, which left us without enough time to actually test and tune it properly.
 
### Process
 
We needed more track time earlier on, since a lot of our biggest issues, like PD tuning, lap counting, and state machine bugs, only ever showed up during real runs and took weeks to fix because we didn't have enough access to a track. Relying so heavily on one person to understand the code was a risk that caught up with us the moment Michael left for China. Ryan and Elvis ended up spending an entire four hour class period just trying to figure out how to even connect to the robot and make a basic code change, since Michael had always been the one handling that part and nobody else really knew the process. If we had shared that knowledge across the whole team earlier, that day alone would have taken twenty minutes instead of four hours.
 
---
 
## Future Improvements
 
### Hardware
 
We want to replace the OV5647 camera with the Raspberry Pi Camera Module 3 Wide, since its higher resolution and 120fps would give the vision pipeline a lot more headroom, especially for the obstacle challenge at higher speeds. We'd also like to design a proper PCB for power distribution instead of relying on point-to-point wiring, which would cut down on failure points and make the electronics a lot more compact and reliable. A LiDAR would also be nice however we did not have enough time to finish fully coding it. We also want to design a proper Ackermann steering geometry to get rid of the tire scrub we get during turns, which should improve how accurately the robot follows its path at higher speeds.
 
### Software
 
We want to build adaptive HSV thresholds that adjust to the lighting automatically instead of needing to be recalibrated by hand before every run. Adding odometry or dead-reckoning using encoder feedback or IMU data would also help lap counting be more reliable and take some of the pressure off relying on vision alone. We still need to finish the parallel parking implementation for the obstacle challenge. We'd also like to properly publish the piclient package to PyPI so setup is just a single pip install instead of needing to build from source every time. Expanding the test suite with more integration tests using recorded video would also let us validate software changes without needing physical track time for every little check.
 
### Process
 
We want to start hardware iteration earlier and run it alongside software development instead of doing them one after the other. We also want to keep a shared calibration log so HSV values and PD gains from each session are actually written down and easy to compare over time instead of living in someone's head. Most importantly, we want to cross-train everyone on both hardware and software so we never end up in a situation like the one after Michael left, where Ryan and Elvis lost a whole class period just trying to figure out how to connect to the robot and push a code change.
 
---
 
## what did we learn?
 
Getting a simple solution working first matters more than building something complicated. We spent a lot of time on a complex pipeline before the basic wall-following was even reliable, and that cost us weeks we could have spent testing.
 
When Michael left for China during late June, Ryan and Elvis sat down to make what should have been a quick code change and ended up spending an entire four hour class just trying to figure out how to even connect to the robot in the first place. Michael had always been the one who handled that side of things, so nobody else really knew the steps. A team where only one person understands the code is a team with a single point of failure, and that class was proof of it.
 
Looking back at the whole build, it definitely wasn't a straight line. Some weeks we felt like we were almost done, other weeks it felt like everything that could break just did.

---

**Heres a photo of Michael hard at work**
<p align="center">
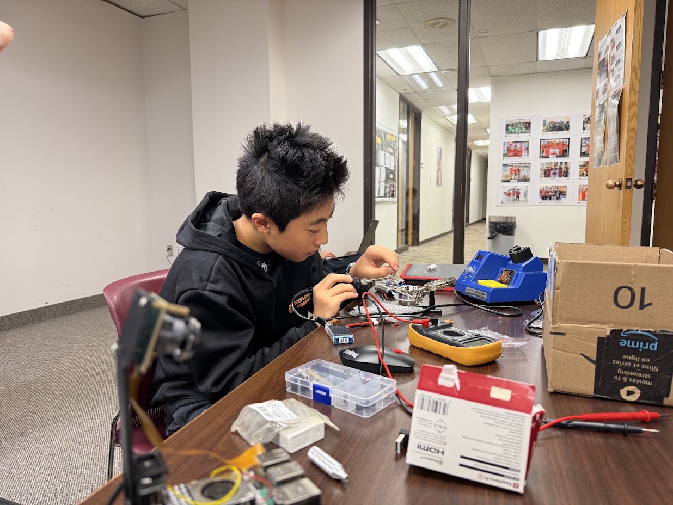
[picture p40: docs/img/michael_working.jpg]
  
</p>
<p align="center">

**Heres a photo of Ryan, Elvis, and our previous teammate last year**
<p align="center">
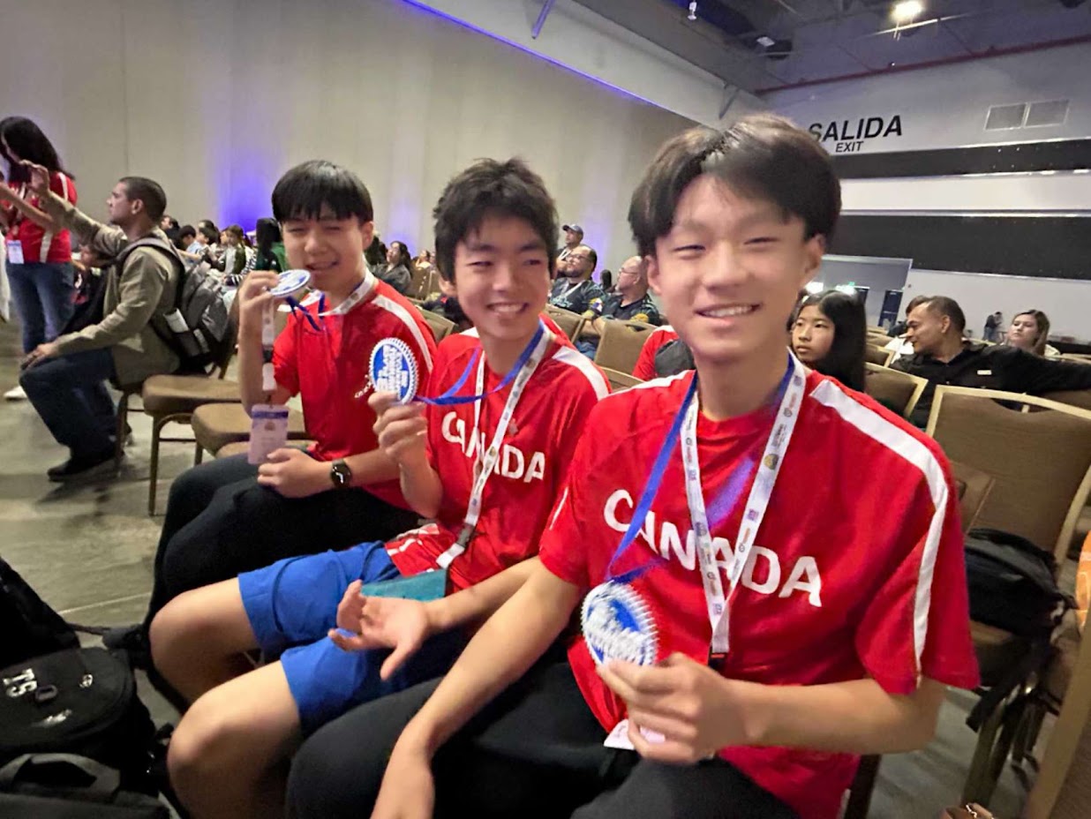
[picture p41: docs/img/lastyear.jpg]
  
</p>
<p align="center">

## Elvis:
 I had an amazing experience working alongside such intellectual and driven peers. This season has probably been my favorite out of the past few. Being surrounded by people who were always willing to share ideas, challenge each other, and help when things got difficult made the experience especially rewarding. I learned a lot from seeing how different people approached problems and worked through challenges.

I also feel that I grew a lot throughout the season, both technically and as a teammate. There were definitely moments where things did not go as planned, but learning how to stay patient, adapt, and work together made those moments some of the most valuable. Looking back, I am really grateful for the people I got to work with and the experiences we shared. This season gave me a lot of memories that I will carry into future seasons. 

I care about Future Engineer because it has taught me so much about engineering while bringing me closer to many incredibly smart and amazing peers who share the same passion.

## Ryan:
I learned a lot from just being around Elvis and Michael. Everyone thought about problems differently, and seeing how they worked through stuff helped me pick up habits I probably wouldn't have learned on my own. The week Michael left for China and I had to figure out the code with Elvis was honestly one of the hardest parts of the season, but it also made me realize how much I actually understood once I was forced to sit with it.

Looking back, this season felt like the one where things finally started making sense. I care about Future Engineers because it's not just about building a robot, it's about learning how to solve real problems with people you actually enjoy working with.

## Michael
I'm the main coder on the team, and thats what I enjoy the most. I sometimes enjoy it a little too much and go overboard on the software :).
I care about Future Engineers because I like coding and this gives me an actual reason to get better at it, plus the team actually calls me out when my explanations don't make sense, which is probably good for me.

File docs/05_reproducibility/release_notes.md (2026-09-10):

v0.1.0-alpha (pre-release) @ 2026-08-26
Preliminary testing release.

*For binaries and source code, please refer to our [GitHub releases page](https://github.com/IaMaAVerYRANdOmPerSoN/WROFutureEngineer/releases/tag/v0.1.0)*

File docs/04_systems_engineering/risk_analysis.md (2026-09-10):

# Risk Analysis

Risk analysis is a critical component of our systems engineering process. It's a key component of our [trade-off analysis](constraints_tradeoffs.md) and [design iteration](iteration_cycles.md) processes, as it allows us to identify potential risks and evaluate their impact on the system. By identifying risks early in the design process, we can take steps to mitigate them before they become major issues.

## Risk Identification

Before we can analyze risks, we must first identify them. We can group risks into four main categories:

1. **Competition Rules**: We review the competition rules to identify any potential risks associated with compliance. This includes understanding the rules and regulations that govern the competition, as well as any penalties for non-compliance.
2. **Physical Limitations**: We consider the physical limitations of the robot, including its size, weight, and power requirements. This includes evaluating the robot's ability to navigate the course, as well as its ability to withstand environmental conditions such as temperature and humidity.
3. **Performance Requirements**: We evaluate the performance requirements of the robot, including its speed, accuracy, and reliability. This includes considering the robot's ability to complete tasks within the required time frame, as well as its ability to perform under varying conditions.
4. **Design Complexity**: We assess the complexity of the robot's design, including its mechanical, electrical, and software components. This includes evaluating the robot's ability to integrate different subsystems, as well as its ability to adapt to changes in the competition environment.

With these categories in mind, we identify specific risks that could impact the robot's performance, reliability, and compliance with competition rules through empirical observation. Critical risks are fixed immediately, while non-critical risks are communicated to the team and monitored for future mitigation.

## Risk Evaluation

Mitigating a risk involves making a trade-off between the risk and the opportunity cost. We follow our rigorous [constraint and trade-off analysis process](constraints_tradeoffs.md) to evaluate the risks and determine the best course of action. We consider the following factors when evaluating risks:

- **Likelihood**: We assess the likelihood of the risk occurring, based on historical data, empirical observation, and expert judgment. This includes considering the probability of the risk occurring, as well as the potential impact on the robot's performance and reliability.
- **Impact**: We evaluate the potential impact of the risk on the robot's performance, reliability, and compliance with competition rules. This includes considering the severity of the consequences if the risk were to occur.
- **Mitigation Strategies**: We develop mitigation strategies to reduce the likelihood and impact of the risk. This includes considering alternative design choices, as well as implementing redundancy and fail-safe mechanisms to ensure that the robot can continue to operate in the event of a failure.

To help us evaluate risks, we use a risk matrix to visualize the likelihood and impact of each risk. This allows us to prioritize risks based on their potential impact on the robot's performance and reliability. The x-axis of the risk matrix represents the likelihood of the risk occurring, while the y-axis represents the impact of the risk on the robot's performance and reliability. Risks that fall in the upper right quadrant of the matrix are considered high-priority risks, while risks that fall in the lower left quadrant are considered low-priority risks.

[ Insert a risk matrix here ]

## Risk Mitigation

The goal of risk mitigation is to reduce the likelihood and impact of risks to an acceptable level. This is achieved through the implementation of various strategies, such as design changes, additional testing, or the use of backup systems. The effectiveness of these strategies is continuously monitored and adjusted as needed to ensure that the robot remains safe and reliable throughout the competition.

Mitigating risk is an iterative process. Once a risk is identified, evaluated, and a mitigation strategy is planned, we implement a preliminary solution and test it on the track. If the mitigation strategy demonstrates the expected results, we begin iterating on the solution to optimize it. If the mitigation strategy does not demonstrate the expected results, we re-evaluate the risk and develop a new mitigation strategy. This iterative approach allows us to continuously improve our risk mitigation strategies and ensure that the robot remains safe and reliable throughout testing and at the competition.

We apply the same iterative approach to risk mitigation as we do to our [design iteration process](iteration_cycles.md). By continuously testing and refining our mitigation strategies, we can ensure that the robot remains safe and reliable throughout the competition.

## Summary

The lifecycle of a risk is similar to the lifecycle of a design trade-off. Once a risk is identified, it is evaluated and a mitigation strategy is developed. The mitigation strategy is then implemented and tested on the track, and the results are used to refine the strategy. This iterative process continues until the risk is mitigated to an acceptable level.

### Our Risk Lifecycle

1. Identify: Detect failure modes via track telemetry, SPICE circuit modeling, or rulebook audits.
2. Evaluate: Measure Likelihood vs. Impact to prioritize critical fixes over minor tweaks.
3. Mitigate: Deploy a "quick and dirty" hardware/software patch first.
4. Validate: Test the patch on the track (SSOT) to confirm the risk is lowered without introducing secondary bugs.
5. Iterate: Optimize the mitigation into the final production design.

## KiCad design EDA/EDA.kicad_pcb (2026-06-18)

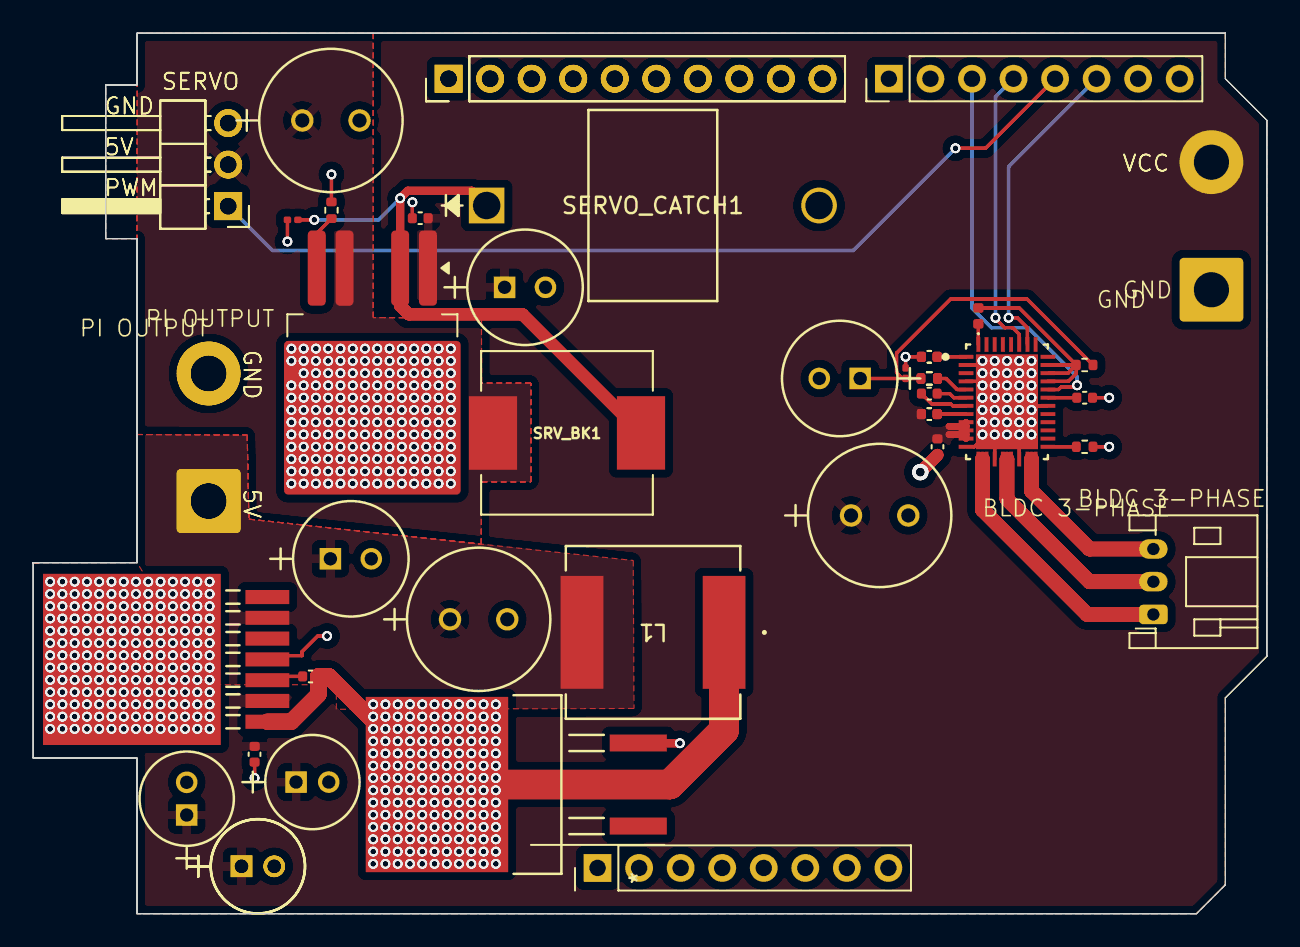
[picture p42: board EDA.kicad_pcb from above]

Board: 2 copper layers, 75.4 x 53.8 mm, 45 parts (0 on the bottom side), 25 nets.

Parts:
ARD_A1: Conn_01x08_Pin; PinHeader_1x08_P2.54mm_Vertical
ARD_B1, ARD_B1#2: Conn_01x10_Pin; PinHeader_1x10_P2.54mm_Vertical
ARD_C1: Conn_01x08_Pin; PinHeader_1x08_P2.54mm_Vertical
AVDD_BYP1: 1uf; C_0402_1005Metric
BK_BULK1: 100uf; CAP_WCAP-ATUL_06.3X11.0_WRE
BK_BYP1: 1uf; C_0201_0603Metric
BLDC_3P1: Conn_01x03_Pin; JST_PH_S3B-PH-K_1x03_P2.00mm_Horizontal
BULK_VM2: 470uf; CAP_YX_8X11P5_RUB
BYP_SRV1: 1uf; C_0402_1005Metric
BYP_VM1: 1uf; C_0402_1005Metric
CP_HL1: 47nf; C_0402_1005Metric
C_BOOST1: 0.01uf; C_0402_1005Metric
C_PUMP1, C_PUMP1#2: 1uf; C_0402_1005Metric
DVDD_BYP1, DVDD_BYP1#2: 1uf; C_0402_1005Metric
D_FAULT1: LED; LED_0402_1005Metric
FG_PU1: 5.1k; R_0402_1005Metric
J2: Screw_Terminal_01x02; SolderWire-1.5sqmm_1x02_P7.8mm_D1.7mm_OD3.9mm
L1: SRP1038WA-220M; IND_SRP1038WA-220M_BRN
M1, M1#2: Motor_Servo; PinHeader_1x03_P2.54mm_Horizontal
PD_SRV1: 5k; R_0402_1005Metric
PI_BULK1, PI_BULK1#2, PI_BULK2, PI_BULK3: 15uf; CAP_5X11_WRE
PI_BYP1: 0.47uf; C_0402_1005Metric
PI_CATCH1: Schotty Diode; DPAK_045S-M3_VIS
PI_OUT1, PI_OUT1#2: Screw_Terminal_01x02; SolderWire-1.5sqmm_1x02_P7.8mm_D1.7mm_OD3.9mm
PI_OUT2: 470uf; CAP_YX_8X11P5_RUB
PI_OUT3: 100uf; CAP_WCAP-ATUL_06.3X11.0_WRE
R1: 5.1k; R_0402_1005Metric
R_BK1, R_BK1#2: 5.1k; R_0402_1005Metric
SERVO_CATCH1: 1N5825; 1N5825_MCH
SRVOUT_BULK1: 470uf; CAP_YX_8X11P5_RUB
SRVOUT_BYP1: 1uf; C_0201_0603Metric
SRV_BK1: 68uh; IND_SPM10065VT-680M-D
SRV_BULK1: 100uf; CAP_WCAP-ATUL_06.3X11.0_WRE
U1: PMCF8316A1VRGFR; RGF0040E-IPC_A
U2: LM2596S-5; TO-263-4
U3: LM2678S-5; TS7B

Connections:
+3V3: BK_BULK1.1, BK_BYP1.1, FG_PU1.1, R_BK1.2, R_BK1#2.2
+7.5V: BULK_VM2.1, BYP_SRV1.2, BYP_VM1.2, C_PUMP1.1, C_PUMP1#2.1, J2.2, PI_BULK1.1, PI_BULK1#2.1, PI_BULK2.1, PI_BULK3.1, PI_BYP1.2, SRV_BULK1.1, U1.9 (VM), U1.10 (VM), U1.11 (VM), U2.1 (VIN), U3.2 (VIN)
GND: ARD_A1.6, ARD_A1.7, AVDD_BYP1.1, BK_BULK1.2, BK_BYP1.2, BULK_VM2.2, BYP_SRV1.1, BYP_VM1.1, DVDD_BYP1.2, DVDD_BYP1#2.2, J2.1, M1.3 (-), M1#2.3 (-), PD_SRV1.1, PI_BULK1.2, PI_BULK1#2.2, PI_BULK2.2, PI_BULK3.2, PI_BYP1.1, PI_CATCH1.3, PI_OUT1.2, PI_OUT1#2.2, PI_OUT2.2, PI_OUT3.2, R1.1, SERVO_CATCH1.2, SRVOUT_BULK1.2, SRVOUT_BYP1.2, SRV_BULK1.2, U1.2 (DGND), U1.4 (GND_BK), U1.12 (PGND), U1.15 (PGND), U1.18 (PGND), U1.26 (AGND), U1.41 (Thermal_Pad), U2.3 (GND), U3.4 (GND), U3.8 (PAD)
unnamed: ARD_C1.3, U1.28 (SPEED_WAKE)
unnamed: ARD_C1.4, U1.35 (BRAKE)
unnamed: ARD_C1.6, U1.34 (DIR)
unnamed: BLDC_3P1.1, U1.13 (OUT_A), U1.14 (OUT_A)
unnamed: BLDC_3P1.2, U1.16 (OUT_B), U1.17 (OUT_B)
unnamed: BLDC_3P1.3, U1.19 (OUT_C), U1.20 (OUT_C)
unnamed: D_FAULT1.2 (A), FG_PU1.2, U1.29 (FG), U1.30 (SDA), U1.31 (SCL)
unnamed: D_FAULT1.1 (K), U1.40 (FAULT_N)
unnamed: AVDD_BYP1.2, U1.27 (AVDD)
unnamed: C_PUMP1.2, C_PUMP1#2.2, U1.8 (CP)
unnamed: CP_HL1.1, U1.7 (CPH)
unnamed: CP_HL1.2, U1.6 (CPL)
unnamed: R1.2, U1.21 (DRVOFF)
unnamed: DVDD_BYP1.1, DVDD_BYP1#2.1, U1.1 (DVDD)
unnamed: R_BK1.1, R_BK1#2.1, U1.5 (SW_BK)
unnamed: SERVO_CATCH1.1, SRVOUT_BYP1.1, SRV_BK1.1, U2.2 (OUT)
unnamed: PD_SRV1.2, U2.5 (~ON/OFF)
unnamed: C_BOOST1.1, U3.3 (BOOST)
unnamed: C_BOOST1.2, L1.1, PI_CATCH1.2, U3.1 (SW)
PI 5V, 5A: L1.2, PI_OUT1.1, PI_OUT1#2.1, PI_OUT2.1, PI_OUT3.1, U3.6 (FB)
SRV 5V, 3A: M1.2 (+), M1#2.2 (+), SRVOUT_BULK1.1, SRV_BK1.2, U2.4 (FB)
SRV_PWM: ARD_C1.5, M1.1 (PWM), M1#2.1 (PWM)

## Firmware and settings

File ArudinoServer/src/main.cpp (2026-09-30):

#include <Arduino.h>
#include <math.h>
#include <Hashtable.h>
#include <L293D.h>
#include <Servo.h>

struct Request {
    int tid;
    String command;
    float arg1;
    float arg2;
    int count;
    unsigned long timeout;
    int processed;
};

#define MOTOR 12   // Motor PWM
#define STEERING_PWM 11 // Servo PWM
#define SERIAL_TIMEOUT 10 // Serial read timeout in milliseconds

Servo steering;
Servo motor;

class CommandServer {
    private:
        Stream* _serial;
        Hashtable<String, Request> currentProcesses;
        SimpleVector<String> commands;
        Servo& _motor;
        Servo& _steering;
        unsigned int _last_packet_time = millis();

        Request parseRequest() {
            Request req = {0, "", 0, 0, 0, 0, 1};
            
            if (_serial->available()) {
                _last_packet_time = millis();
                String line = _serial->readStringUntil('\n');
                line.trim();
                if (line.length() == 0) {
                    return req;
                }
                char serialBuff[32] = {0};
                char arg1Buff[32] = {0};
                char arg2Buff[32] = {0};

                req.count = sscanf(line.c_str(), "%d %31s %31s %31s", &req.tid, serialBuff, arg1Buff, arg2Buff);
                if (req.count < 2) {
                    req.tid = 0;
                    return req;
                }
                req.command = String(serialBuff);
                if (req.count >= 3) {
                    req.arg1 = atof(arg1Buff);
                }
                if (req.count >= 4) {
                    req.arg2 = atof(arg2Buff);
                }
                req.processed = 0;
            }
            return req;
        }

        void start(Request& request) {
            String prefix = String(request.tid) + " ";

            if (request.command == "PING") {
                request.timeout = 0;
                request.processed = 1;
                end("PING");
            } 
            else if (request.command == "SET_SERVO") {
                unsigned int current_angle = _steering.read();
                unsigned long duration = fabs(request.arg1 - current_angle);
                request.timeout = millis() + duration;
                _serial->println(prefix + "WAITMS " + String(duration));
                _steering.write(request.arg1);
            } 
            else if (request.command == "INC_SERVO") {
                unsigned long duration = (unsigned long)(request.arg1);
                request.timeout = millis() + duration;
                _serial->println(prefix + "WAITMS " + String(duration));
                _steering.write(_steering.read() + request.arg1);
            }
            else if (request.command == "SET_MOTOR") {
                unsigned long duration = (unsigned long)(fabs(request.arg2) * 1000.0f + 0.5f);
                request.timeout = millis() + duration;
                _serial->println(prefix + "WAITMS " + String(duration));
                _motor.writeMicroseconds(1500 + (int)(request.arg1 * 300.0f / 100.0f)); // Speed passed in percent
            }
            else if (request.command == "SET_LED") {
                request.timeout = 0;
                request.processed = 1;
                if (request.arg1 > 1e-6) {
                    digitalWrite(6, HIGH);
                } else {
                    digitalWrite(6, LOW); // Only 1 is on
                }
                end("SET_LED");
            } 
            else if (request.command == "SERVO_ANGLE") {
                request.timeout = 0;
                request.processed = 1;
                end("SERVO_ANGLE");
            }
            else {
                _serial->println(prefix + "404 ERR");
                end("404 ERR");
            }
        }

        void end(String command) {
            Request& request = currentProcesses[command];
            String prefix = String(request.tid) + " ";

            if (command == "PING") {
                _serial->println(prefix + "PONG");
            } else if (command == "SET_SERVO") {
                _serial->println(prefix + "200 OK");
            } else if (command == "INC_SERVO") {
                _serial->println(prefix + "200 OK");
            } else if (command == "SET_MOTOR") {
                _motor.writeMicroseconds(1500); // Stop the motor
                _serial->println(prefix + "200 OK");
            } else if (command == "SET_LED") {
                // Keep the led's current state
                _serial->println(prefix + "200 OK");
            } else if (command == "SERVO_ANGLE") {
                _serial->println(prefix + _steering.read());
            } else if (command == "404 ERR") {}
        }
        
    public:
        CommandServer(Stream& s, Servo& motor, Servo& steering) : _serial(&s), _motor(motor), _steering(steering) {
            commands.push_back("PING");
            commands.push_back("SET_SERVO");
            commands.push_back("INC_SERVO");
            commands.push_back("SET_MOTOR");
            commands.push_back("SET_LED");
            commands.push_back("SERVO_ANGLE");
        }

        void processRequest() {
            Request incoming = parseRequest();
            if (incoming.count >= 2) {
                currentProcesses[incoming.command] = incoming;
                start(currentProcesses[incoming.command]);
            }

            for (auto &cmd : commands) {
                Request& req = currentProcesses[cmd];
                
                if (req.timeout != 0 && req.processed == 0 && millis() >= req.timeout) {
                    end(cmd);
                    req.processed = 1; 
                }
            }
        }
        
        bool isIdle(unsigned int idleTime) {
            return (millis() - _last_packet_time) > idleTime;
        }

        void stop() {
            _motor.writeMicroseconds(1500); // Stop the motor without generating responses.
            currentProcesses.clear();
        }
};

CommandServer* server;

void setup() {
    pinMode(6, OUTPUT); // LED

    Serial.begin(115200);
    Serial.setTimeout(SERIAL_TIMEOUT); // Keep parser responsive when lines arrive in chunks.
    steering.attach(STEERING_PWM);
    motor.attach(MOTOR);
    motor.writeMicroseconds(1500); // Stop the motor
    delay(1000); // give the motor some time to stop before accepting commands
    server = new CommandServer(Serial, motor, steering);
}

void loop() {
    server->processRequest();
    if (server->isIdle(40)) { // 30fps is 33ms, so 40ms is a safe threshold for idle detection
        server->stop();
    }
}


/*#include <Arduino.h>
#include <Servo.h>

#define STEERING_PWM 11 // Servo PWM

Servo steering;

void setup() {
    steering.attach(STEERING_PWM);
    steering.write(90);
}

void loop() {}*/

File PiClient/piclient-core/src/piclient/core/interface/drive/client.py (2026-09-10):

"""Serial communication protocol client.

Provides :class:`Client` for request/response communication with the
Arduino over async serial, and :class:`DriveCommandExecutor` for
coalescing drive commands with latest-wins semantics.
"""

from typing import Any, Literal, NoReturn, Self

import asyncio
import re
from itertools import cycle
from collections.abc import Coroutine
from collections import defaultdict

import aioserial

from loguru import logger
from ...lib import GLOBAL_CONFIG, export


@export
class Client:
    """Async serial client used by the drive command executor.

    This is the drive-interface client and is distinct from the lower-level
    :class:`piclient.core.interface.comm_protocol.Client`; both speak the same
    request/response protocol but expose separate package APIs.

    :ivar _serial: Underlying :class:`aioserial.AioSerial` instance.
    :ivar port: Serial port path.
    :ivar baud: Serial baud rate.
    :ivar timeout: Default timeout for granular requests.
    :ivar TIDS: Cyclic transaction ID generator.
    :ivar is_connected: Whether the Arduino handshake has succeeded.
    """

    def __init__(
            self,
            port: str = GLOBAL_CONFIG().ClientConfig.SERIAL_PORT,
            baud: int = GLOBAL_CONFIG().ClientConfig.SERIAL_BAUD,
            timeout: float = GLOBAL_CONFIG().ClientConfig.SERIAL_TIMEOUT,
            retries: int = GLOBAL_CONFIG().ClientConfig.CONNECT_RETRIES,
            max_speed: int = GLOBAL_CONFIG().ClientConfig.MAX_SPEED,
            tid_start: int = GLOBAL_CONFIG().ClientConfig.TID_START,
            tid_end: int = GLOBAL_CONFIG().ClientConfig.TID_END,
            wait_re_pattern: str = GLOBAL_CONFIG().ClientConfig.WAIT_RE_PATTERN,
            trim: int = GLOBAL_CONFIG().ClientConfig.SERVO_TRIM,
            loop: asyncio.AbstractEventLoop | None = None,
    ):
        """
        Construct a client without opening the serial device.

        :param port: The serial port passed to `aioserial.AioSerial`.
        :param baud: The baudrate of the serial protocol.
        :param timeout: Default timeout for granular requests.
        :param tid_start: First transaction ID (inclusive).
        :param tid_end: Last transaction ID (inclusive) before cycling.
        :param wait_re_pattern: Regex pattern for Arduino ``WAITMS`` responses.
        :param trim: Servo trim value applied by servo commands.
        :param retries: Number of connection attempts used by
            :meth:`verify_connection`.
        :param max_speed: Absolute motor speed represented by normalized speed
            ``1.0``.
        :param loop: Event loop used for request futures; defaults to the
            current event loop.

        :returns self: an instance of `Client`
        """

        self._serial = None
        self.port, self.baud = port, baud
        self.timeout: float = timeout
        self.retries: int = retries
        self._tids: cycle[int] = cycle(
            [i for i in range(tid_start, tid_end + 1)])
        self.max_speed: int = max_speed
        self._wait_re: re.Pattern[str] = re.compile(wait_re_pattern)
        self.is_connected = False
        self.trim: int = trim

        self.loop: asyncio.AbstractEventLoop = loop if loop else asyncio.get_event_loop()

        self._pending_requests: defaultdict[str, asyncio.Future[tuple[str, str]]] = defaultdict(
            asyncio.Future)  # {TID: future} -> {TID: response}
        self._lock = asyncio.Lock()
        self._drive_semaphore = asyncio.BoundedSemaphore(1)
        self.servo_angle = 0

        logger.info(
            f"======= CLIENT INSTANCE STARTED: Port = {self.port}, Baud = {self.baud}, Timeout = {self.timeout} ======= ")

    async def _serial_listener(self) -> NoReturn:
        """Background task that reads lines from serial and resolves pending futures.

        Each incoming line is parsed for a transaction ID (TID); if a pending
        future exists for that TID, the line is delivered as its result.

        :param self: The instance of :class:`Client`.
        :returns: This coroutine runs indefinitely and never returns normally.
        :raises AssertionError: If the serial interface is not initialized.
        """
        assert self._serial is not None, "Serial interface not initialized. Did you forget to use the async context manager?"

        while True:
            line: bytes = await self._serial.readline_async()
            response: str = line.decode('utf-8').strip()

            logger.debug(f"Line read from serial buffer: '{response}'")

            parts: list[str] = response.split(" ", 1)
            if len(parts) < 2:
                continue

            tid, message = parts[0], parts[1]

            if tid in self._pending_requests:
                future: asyncio.Future[tuple[str, str]
                                       ] = self._pending_requests[tid]
                if not future.done():
                    future.set_result((tid, message))

    async def __aenter__(self) -> Self:
        """
        Async context manager entry point that initializes the serial interface
        and starts the background serial listener task.

        :param self: The instance of `Client`
        :return: The current `Client` instance.
        :rtype: Client
        """
        self._serial = aioserial.AioSerial(
            self.port, self.baud, timeout=self.timeout)

        loop: asyncio.AbstractEventLoop = asyncio.get_event_loop()
        loop.set_exception_handler(lambda loop, context: None)

        if not hasattr(self, "_listener_task"):
            self._listener_task: asyncio.Task[NoReturn] = asyncio.create_task(
                self._serial_listener())
            logger.info("Serial Listener Started")
        else:
            logger.warning("Serial listener already started in this context")
        return self

    async def __aexit__(self, *args: Any) -> None:
        """
        Async context manager exit point that cancels the background serial
        listener task and closes the serial connection.

        :param self: The instance of `Client`
        :param args: Exception type, value, and traceback (per context manager protocol).
        """
        if hasattr(self, "_listener_task"):
            self._listener_task.cancel()
            self._serial.close() if self._serial else None
            logger.info("Serial listener terminated without errors")
        else:
            logger.warning("No serial listener to cancel")

    async def reload(self) -> Self:
        """Hot reload after changing attributes.

        Tears down existing hardware resources, reinitialises the client
        with the updated configuration, and cleans up on failure before
        re-raising

        ALWAYS call after changing attributes to reload internal context.
        Not doing so will lead to unpredictable behaviour.
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

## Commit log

2025-12-29 Created Asyncronous wrapper for PiCamera2, Developed obstacle detection and field boundary check
    - Async Camera wrapper opened with __aenter__ and __aexit__ methods, supports fetching single live frames, buffering frames, and live IOstreaming
    - New VisionProcessor() class finds obstacles and field bondaries with a binary mask using YUV colorspace
    - VisionObject class acts a struct to easily store and access contour data following OOP conventions.
2026-06-18 Add footprints for RGF0040E components and update documentation
    - Created new footprint files for RGF0040E-IPC_C and RGF0040E-MFG in KiCAD format.
    - Established a project plan document outlining milestones and tasks for upcoming development phases.
    Add LM2678S-12 symbol and footprints to KiCAD library
    - Created a new symbol for the LM2678S-12 in the KiCAD symbol library.
    - Added three footprints (TS7B, TS7B-L, TS7B-M) for the LM2678S-12 in the KiCAD footprint library.
    - Each footprint includes detailed pad and line definitions, along with silk screen and courtyard outlines.
    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
    [EDA.csv, EDA.kicad_pcb, EDA.kicad_sch]
2026-06-18 Update platformio.ini and main.cpp to include new motor and servo libraries; Modify AsyncCamera for higher resolution and adjust CommProtocol for increased max speed; Add tests for camera functionali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
2026-06-18 Add initial EDA project files and configuration
    - Created EDA.step file for project steps.
    - Added autosave configuration for EDA.kicad_prl with board settings, visibility options, and net inspector panel configurations.
    - Introduced lock files for PCB and schematic with hostname and username information.
    Add components table to README
    Added a table listing various components with their products and prices.
    Add new symbols and footprints for UCY2D181MHD3TN and VS-6TQ045S-M3 components
    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
    [BOM.csv, EDA.csv, EDA.kicad_pcb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]
2026-06-18 Add footprints for RGF0040E and LM2678S-12 components and update documentation
    - Updated properties for reference, value, and datasheet links in the symbol and footprints.
    - Refactor schematic for clarity and readablity.
    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
    [EDA.csv, EDA.kicad_sch]
2026-06-18 Add No-Connect flags and add labels, create ground terminal for Raspberry Pi.
    [EDA.kicad_sch]
2026-06-18 Started Routing PCB.
    - Developed Pi 5V, 5A power supply.
    - Working on 5V, 3A servo power supply.
    - Yet to begin wiring BLDC motor controller logic.
    [EDA.kicad_pcb, EDA.kicad_sch, EDA.step]
2026-06-18 Add new symbols and footprints for UCY2D181MHD3TN and VS-6TQ045S-M3 components
    - Created symbol for UCY2D181MHD3TN with properties including reference, value, footprint, and datasheet.
    - Added footprint for UCY2D181MHD3TN with dimensions and pad specifications.
    - Created symbol for VS-6TQ045S-M3 with properties including reference, value, footprint, and datasheet link.
    - Added multiple footprints for VS-6TQ045S-M3, including DPAK_045S-M3_VIS, DPAK_045S-M3_VIS-L, and DPAK_045S-M3_VIS-M with detailed specifications.
    [EDA.csv, EDA.kicad_pcb, EDA.kicad_sch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]
2026-06-18 Refactor project structure and implement asynchronous vision processing
    - Updated import paths to reflect new project structure.
    - Renamed main test function to `run_tests` for clarity.
    - Enhanced vision processing with new detection and drawing functions.
    - Added Docker support with a Dockerfile and entrypoint script.
    - Created requirements.txt for dependency management.
    - Implemented asynchronous camera handling with shared memory.
    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
    [EDA.kicad_sch]
2026-06-18 Fix multiprocessing logic bugs and add additional checks for laeks
    [main.cpp]
2026-06-18 Refactor challenges and enhance obstacle avoidance logic
    - Updated main entry point to support selecting between open and obstacle challenges.
    - Introduced `run_obstacle_challenge` function to handle obstacle avoidance logic.
    - Modified `run_open_challenge` to include hybrid state management.
    - Enhanced vision processing to differentiate between wall and obstacle detection.
    - Added new configuration parameters for obstacle challenge speeds and behaviors.
    - Cleaned up logging for better debugging and state tracking.
    - Removed unused methods and optimized existing ones for clarity and performance.
    [commProtocol.py, main.cpp]
2026-06-18 Refactored main package; Moved all modules to /piclient/src/modules except __main__, __init__ , open challenge and obstacle challenge. Fixed bugs in utils and added cross platfrom compatbility for ut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
    [commProtocol.py, lidar.py]
2026-06-18 Refactor camera configuration and processing; update frame handling in AsyncCamera, VisionProcessor, and related tests; improve import structure across utility modules.
2026-06-18 Refactor objectives in objectives.md; enhance LiDAR integration in code and tools; implement async LiDAR reading and processing; add unit tests for LiDAR functionality; Move subprocess context manage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
2026-07-04 Enhance configuration handling and error tracking
    - Updated TypeVar definition for stricter typing in argument parser.
    - Added Sentry SDK initialization for error tracking in core module.
    - Improved TOML configuration loading with error handling in runner modules.
    - Removed deprecated load_configuration function and ensured configuration is frozen after loading.
    - Added tests for CLI, TOML, and environment variable loading
    [lidar.py]
2026-08-02 Add drive around and obstacle challenge video tools; remove obsolete base tool and contour visualization tools
    - Introduced `drive_around.py` for manual robot control using keyboard inputs.
    - Added `obstacle_challenge_video.py` as a CLI wrapper for obstacle challenge video functionality.
    - Removed `base_tool.py`, `contour_binary.py`, `contours.py`, `control.py`, `lidar.py`, and `raw.py` as they are no longer needed.
    - Cleaned up the project structure by eliminating unused tools and consolidating functionality.
    [async_camera.py, client.py]
2026-08-23 feat: Enhance obstacle challenge logging and replay functionality, complete parallel parking, and update docstrings.
    - Added detailed docstrings to DriveCommand and LogRecord classes for better clarity on their purpose and usage.
    - Improved PickleLogWriter with enhanced documentation and error handling.
    - Implemented build_log_record function with comprehensive docstring for creating LogRecord instances.
    - Updated load_log_records function to include error handling and documentation for loading LogRecord objects.
    - Enhanced format_log_record and draw_replay_overlay functions with detailed docstrings for better understanding.
    - Refactored replay_video function to improve documentation and err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
    [async_camera.py, comm_protocol.py]
2026-09-10 set up WRO repo structure with written README, mechanical docs, and power sensor docs. Added unedited software docs, systems docs reproducibility docs.
2026-09-10 Fix links in README, enhance power architecture details, and add recent journal entries.
2026-09-10 Enhance power architecture documentation, update sensor selection details. Add img folder, building instructions folder, and finished differential gear assembly instructions.
2026-09-10 Updated software, sensor, and journal docs. Also added missing files and file link errors
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2026-09-10 Add Bill of Materials for robot components
    This document details all components used in the robot's construction, including electronics, mechanical parts, and tools required, along with their purposes, quantities, and estimated costs.
2026-09-10 Update documentation: add contributing guidelines, assembly instructions, and release notes; modify bill of materials; remove obsolete files
2026-09-10 Enhance iteration cycles section with differential gear design and python packaging iterations, revise setup guide for clarity, remove obsolete RyanREADME.md, and delete unused GitHub pages config fi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
2026-09-10 Fixed 3D printed parts links
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2026-10-05 Update team member information and fix link case
    Added personal introductions for team members and corrected link case sensitivity.
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2026-10-07 Document weekly updates on journal
    Updated the changelog with weekly progress on the microcontroller transition from Arduino Uno to Arduino Nano, including design changes and issues encountered with IMU readings.
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2026-10-07 Replace Arduino Uno with Arduino Nano in power table
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2026-10-07 Fix IMU section in README
    Corrected IMU description and updated links.
